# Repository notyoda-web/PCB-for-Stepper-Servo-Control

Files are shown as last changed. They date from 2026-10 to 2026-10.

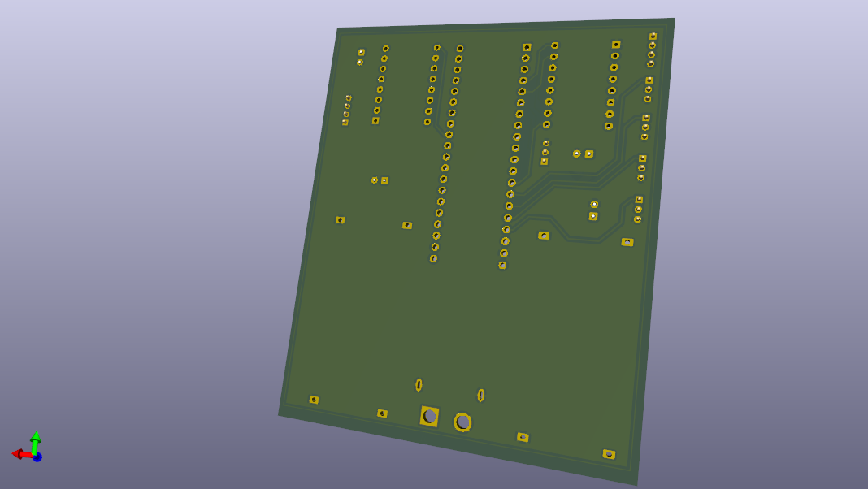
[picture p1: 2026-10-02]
testeurobot1.png

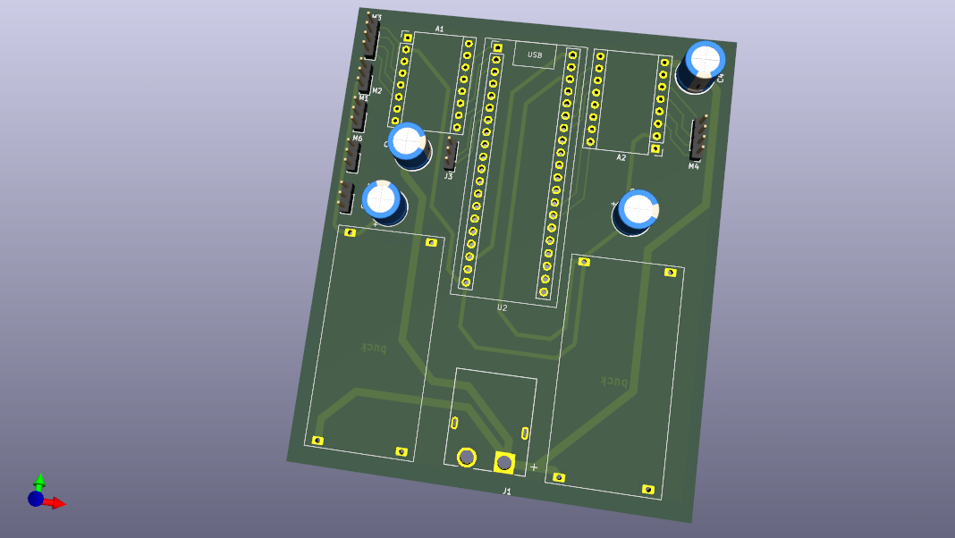
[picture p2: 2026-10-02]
testeurobot.png

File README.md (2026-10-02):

# STM32 Black Pill Stepper & Servo Control Board - Pin Mapping & Connections

This document details the exact pin-to-pin net connections and interface routing between the STM32 Black Pill microcontroller, the power subsystems, the A4988 stepper drivers, the servo headers, and communication peripherals, as established in the KiCad schematic .

---

## Power Input & Regulation Subsystem

* **J1 (XT60PW-M Power Input):**
  * Pin `P` (Positive / 12V rail): Connects directly to the main 3S LiPo battery input line, feeding the input terminals of both buck converters (`12V`) and the VMOT pins of A4988 drivers `A1` and `A2`.
  * Pin `N` (Negative / GND): Connects to the system common ground (`GND`).
* **3.3V Buck Converter:**
  * Input: Connected to `12V` rail from J1.
  * Output: Connected to the `3.3V` net, providing power to the Black Pill `VDD`/`3.3V` pins and auxiliary logic. Bulk smoothing capacitor `C1` is placed across the output.
* **5V Buck Converter:**
  * Input: Connected to `12V` rail from J1.
  * Output: Connected to the `5V` net, supplying power to the four hobby servo motor headers (`N1`, `N2`, `N5`, `N6`). Bulk smoothing capacitor `C2` is placed across the output.

---

# Power Distribution & Decoupling Rationale

This document outlines the engineering reasons for using dual buck converters and four electrolytic capacitors in the STM32 Black Pill stepper and servo control board, as shown in the schematic and PCB layout.

---

## 1. The Use of Two Buck Converters

The board utilizes two separate step-down (buck) converters fed by the 3S LiPo battery (`12V` net) to establish distinct power domains:

* **Isolation of Inductive Noise:** Stepper motors and hobby servos generate massive voltage transients, back-EMF, and high-frequency current spikes on their power rails during switching and stalling. By separating the regulation paths, noisy high-power actuator rails are prevented from coupling directly into sensitive digital logic.
* **Dedicated Voltage Domains:** 
  * **5V Buck Converter:** Powers the four hobby servos (`N1`, `N2`, `N5`, `N6`), which draw heavy peak currents under load. Supplying them from a dedicated regulator prevents voltage sags from resetting the microcontroller.
  * **3.3V Buck Converter:** Supplies a clean, stable regulated voltage exclusively to the Black Pill microcontroller (`VDD`/`3.3V`), protecting its internal ADC, core logic, and communication peripherals from brownouts.

---

## 2. The Use of Four Electrolytic Capacitors (`C1`, `C2`, `C3`, `C4`)

The four bulk electrolytic capacitors serve specific filtering and energy-storage functions across the power architecture:

* **Regulator Output Smoothing (`C1` and `C2`):**
  * **`C1` (3.3V Rail):** Placed at the output of the 3.3V buck converter to filter out residual switching ripple, ensuring a steady, low-noise supply for the Black Pill.
  * **`C2` (5V Rail):** Positioned at the 5V regulator output to provide bulk charge reservoirs that instantly compensate for current surges when servos suddenly start moving or change direction.
* **Motor Driver Local Decoupling (`C3` and `C4`):**
  * **`C3` and `C4` (VMOT Decoupling):** Connected directly across the motor supply (`VMOT`) and ground (`GND`) of the two A4988 driver modules (`A1` and `A2`). 
  * **Transient Suppression:** Stepper drivers rapidly chop high currents through inductive windings, creating high-frequency voltage spikes that can destroy silicon. These bulk capacitors act as local energy buffers right next to the driver chips, absorbing back-EMF spikes and stabilizing the input voltage during rapid microstepping steps.

## Stepper Motor Subsystem (A4988 Drivers & Connectors)

* **Driver A1 (Left Stepper Driver):**
  * **Power & Decoupling:** `VMOT` connected to `12V` with electrolytic decoupling capacitor `C3` tied to `GND`; `VDD` connected to `3.3V`.
  * **Control Pins:** 
    * `STEP` $\rightarrow$ Connected to MCU pin `PA1`.
    * `DIR` $\rightarrow$ Connected to MCU pin `PA2`.
    * `ENABLE` $\rightarrow$ Connected to MCU pin `PA6`.
    * Microstepping (`MS1`, `MS2`, `MS3`) $\rightarrow$ Tied to MCU pins `pb2`, `pb1`, `pb0` respectively.
    * `SLEEP` & `RESET` $\rightarrow$ Tied together on the module.
  * **Motor Output (`N4`):**
    * Pins `1B`, `1A`, `2A`, `2B` mapped directly from A1 driver pins 3, 4, 5, 6 to motor connector `N4` (`1A1_181`, `1A`, `2A`, `2B`).

* **Driver A2 (Right Stepper Driver):**
  * **Power & Decoupling:** `VMOT` connected to `12V` with electrolytic decoupling capacitor `C4` tied to `GND`[cite: 3]; `VDD` connected to `3.3V`.
  * **Control Pins:**
    * `STEP` $\rightarrow$ Connected to MCU pin `PB15`.
    * `DIR` $\rightarrow$ Connected to MCU pin `PB14`.
    * `ENABLE` $\rightarrow$ Connected to MCU pin `PB5`.
    * Microstepping (`MS1`, `MS2`, `MS3`) $\rightarrow$ Tied to MCU pins `pb14` (shared/routed), `pb13`, `pb12`.
    * `SLEEP` & `RESET` $\rightarrow$ Tied together on the module.
  * **Motor Output (`N3`):**
    * Pins `1B`, `1A`, `2A`, `2B` mapped directly from A2 driver pins to motor connector `N3`.

---

## Servo Motor Subsystem

All four servo headers share a common power (`5V`) and ground (`GND`) bus, with individual PWM control lines driven directly by MCU GPIO/timer pins:

* **Servo Header N2:** Pin 1 (Signal) $\rightarrow$ MCU pin `PB6`; Pin 2 $\rightarrow$ `5V`; Pin 3 $\rightarrow$ `GND`.
* **Servo Header N1:** Pin 1 (Signal) $\rightarrow$ MCU pin `PB7`; Pin 2 $\rightarrow$ `5V`; Pin 3 $\rightarrow$ `GND`.
* **Servo Header N6:** Pin 1 (Signal) $\rightarrow$ MCU pin `PB8`; Pin 2 $\rightarrow$ `5V`; Pin 3 $\rightarrow$ `GND`.
* **Servo Header N5:** Pin 1 (Signal) $\rightarrow$ MCU pin `PB9`; Pin 2 $\rightarrow$ `5V`; Pin 3 $\rightarrow$ `GND`.

---

## Communication Interface (UART)

* **J3 (UART Header):**
  * Pin 1 (`Rx`) $\rightarrow$ Connected to Black Pill MCU pin `PA9` (`Tx` of USART1) for host ingestion.
  * Pin 2 (`Tx`) $\rightarrow$ Connected to Black Pill MCU pin `PA10` (`Rx` of USART1) for telemetry transmission.
  * Pin 3 (`GND`) $\rightarrow$ Connected to system common ground (`GND`).

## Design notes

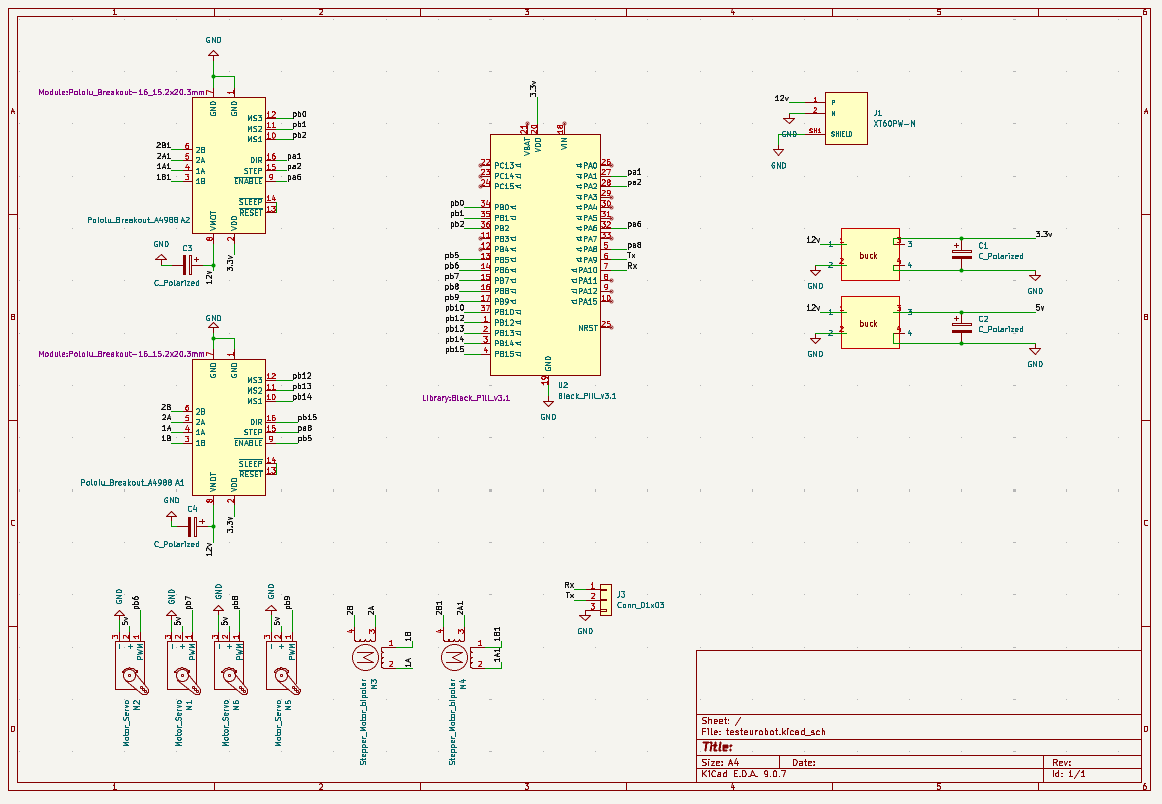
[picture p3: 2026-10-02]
Capture d'écran 2026-10-02 215708.png

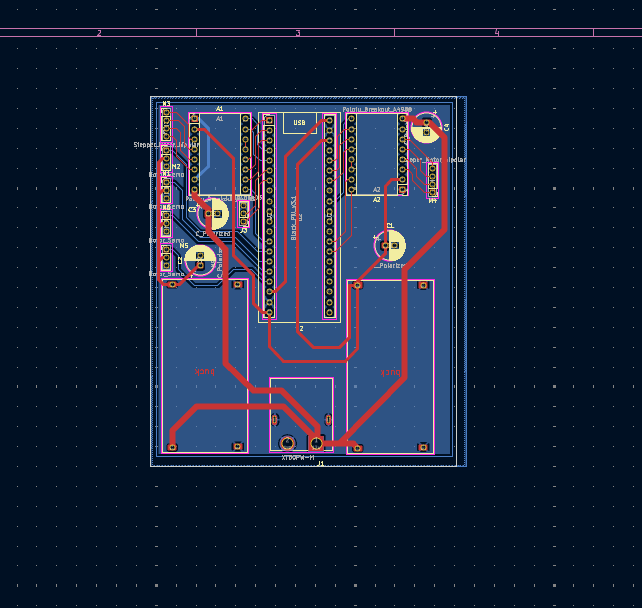
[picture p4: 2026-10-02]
Capture d'écran 2026-10-02 215855.png

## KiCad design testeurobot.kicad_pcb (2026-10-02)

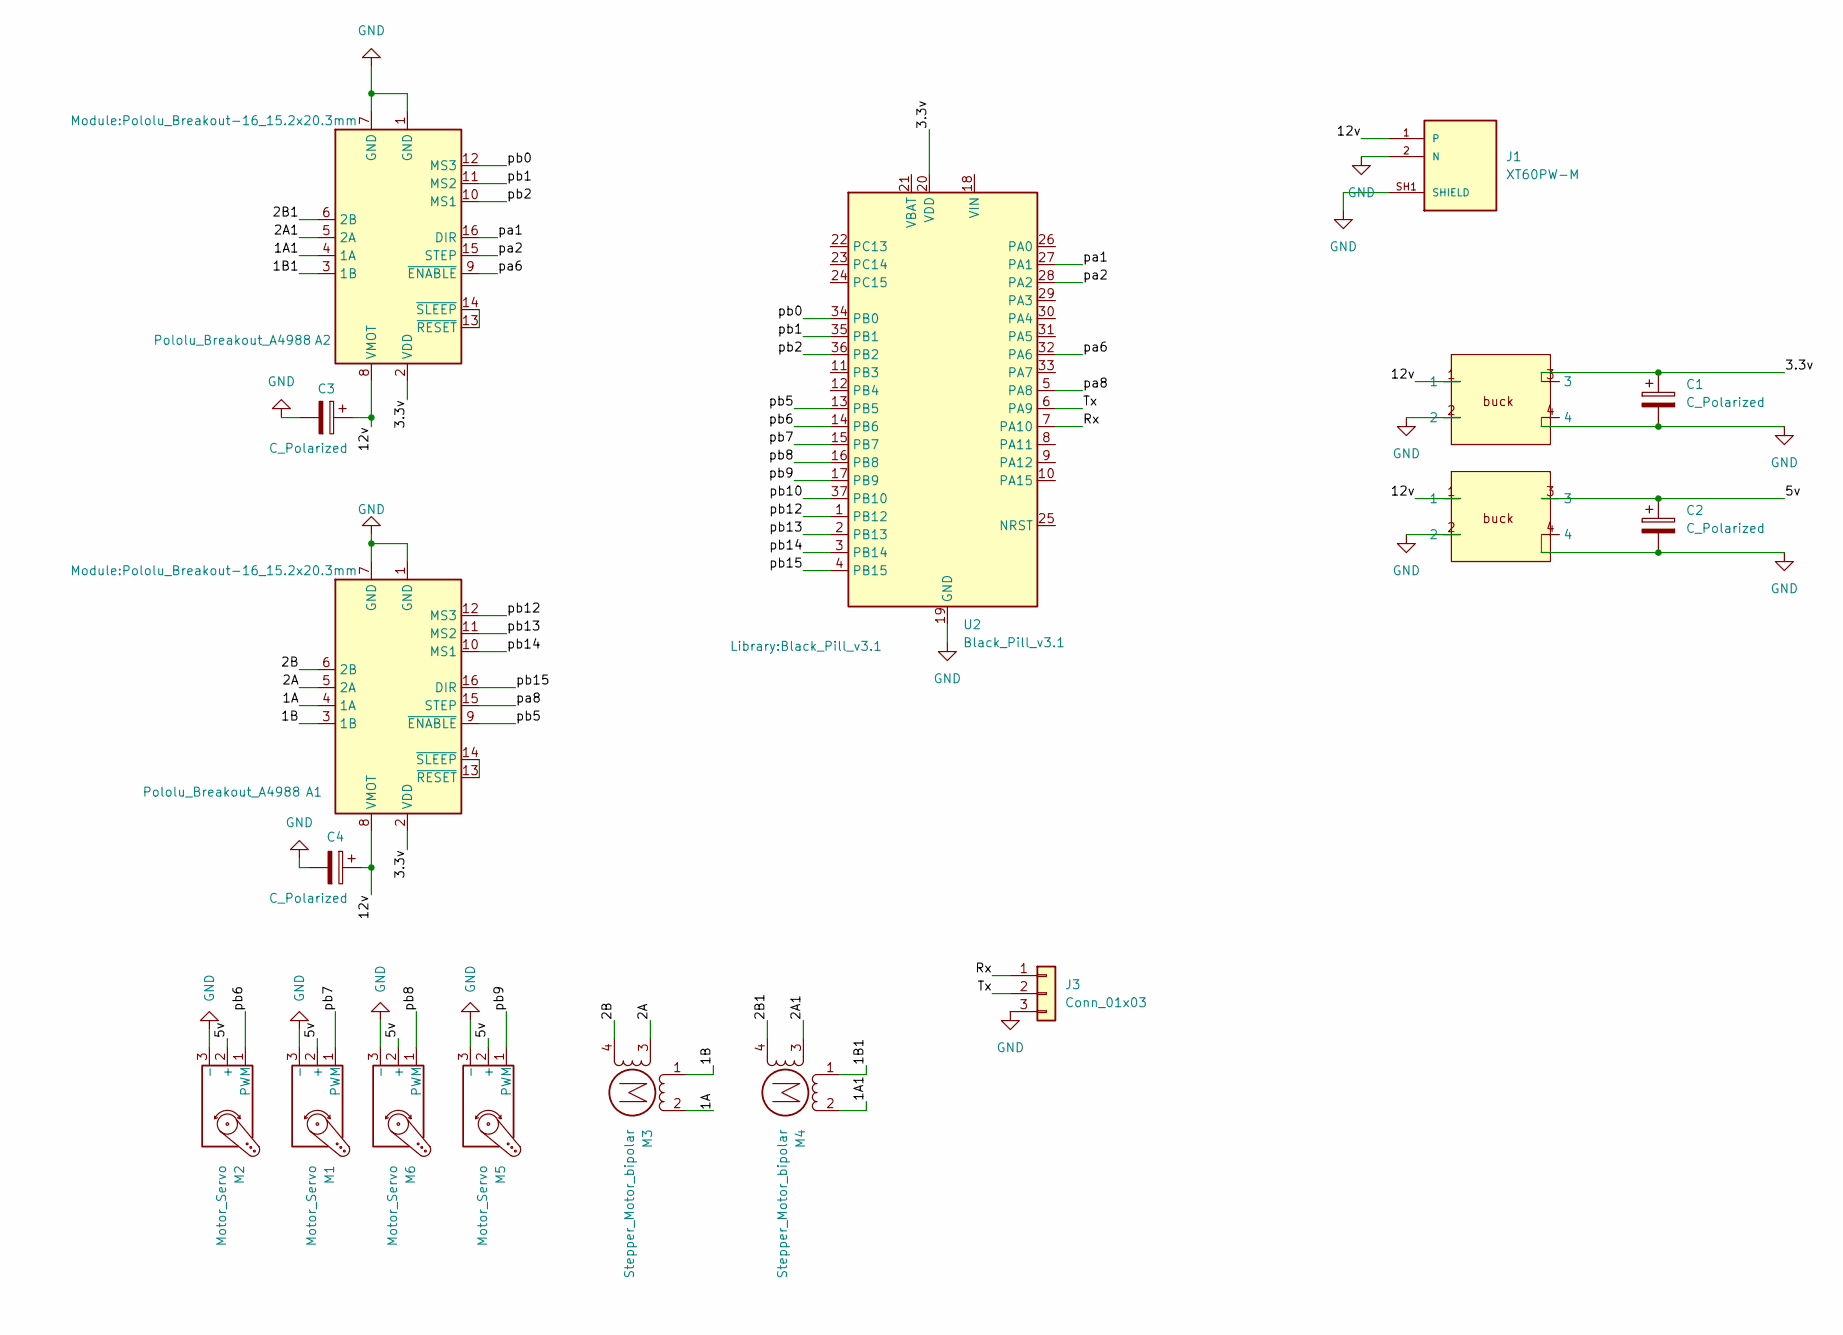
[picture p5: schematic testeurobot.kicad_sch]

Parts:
A1, A2: Pololu_Breakout_A4988; Pololu_Breakout-16_15.2x20.3mm
C1, C2, C3, C4: C_Polarized; CP_Radial_D7.5mm_P2.50mm
J1: XT60PW-M; AMASS_XT60PW-M; PARTREV 1.2
J3: Conn_01x03; PinHeader_1x03_P2.00mm_Vertical
M1, M2, M5, M6: Motor_Servo; PinHeader_1x03_P2.00mm_Vertical
M3, M4: Stepper_Motor_bipolar; PinHeader_1x04_P2.00mm_Vertical
U1, U3: buck
U2: Black_Pill_v3.1

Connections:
/1A: A1.4 (1A), M3.2 (-)
/1A1: A2.4 (1A), M4.2 (-)
/1B: A1.3 (1B), M3.1
/1B1: A2.3 (1B), M4.1
/2A: A1.5 (2A), M3.3
/2A1: A2.5 (2A), M4.3
/2B: A1.6 (2B), M3.4
/2B1: A2.6 (2B), M4.4
/5v: C2.1, M1.2 (+), M2.2 (+), M5.2 (+), M6.2 (+), U3.3
/12v: A1.8 (VMOT), A2.8 (VMOT), C3.1, C4.1, J1.1, U1.1, U3.1
/Rx: J3.1, U2.7 (PA10)
/Tx: J3.2, U2.6 (PA9)
/pa1: A2.16 (DIR), U2.27 (PA1)
/pa2: A2.15 (STEP), U2.28 (PA2)
/pa6: A2.9 (~ENABLE), U2.32 (PA6)
/pa8: A1.15 (STEP), U2.5 (PA8)
/pb0: A2.12 (MS3), U2.34 (PB0)
/pb1: A2.11 (MS2), U2.35 (PB1)
/pb2: A2.10 (MS1), U2.36 (PB2)
/pb5: A1.9 (~ENABLE), U2.13 (PB5)
/pb6: M2.1 (PWM), U2.14 (PB6)
/pb7: M1.1 (PWM), U2.15 (PB7)
/pb8: M6.1 (PWM), U2.16 (PB8)
/pb9: M5.1 (PWM), U2.17 (PB9)
/pb10: U2.37 (PB10)
/pb12: A1.12 (MS3), U2.1 (PB12)
/pb13: A1.11 (MS2), U2.2 (PB13)
/pb14: A1.10 (MS1), U2.3 (PB14)
/pb15: A1.16 (DIR), U2.4 (PB15)
GND: A1.1 (GND), A1.7 (GND), A2.1 (GND), A2.7 (GND), C1.2, C2.2, C3.2, C4.2, J1.2 (N), J1.SH1 (SHIELD), J1.SH2 (SHIELD), J3.3, M1.3 (-), M2.3 (-), M5.3 (-), M6.3 (-), U1.2, U1.4, U2.19 (GND), U2.39 (GND), U3.2, U3.4
unnamed: A1.13 (~RESET), A1.14 (~SLEEP)
unnamed: A2.13 (~RESET), A2.14 (~SLEEP)
VDD: A1.2 (VDD), A2.2 (VDD), C1.1, U1.3, U2.20 (VDD), U2.38 (VDD)
VIN: U2.18 (VIN), U2.40 (VIN)

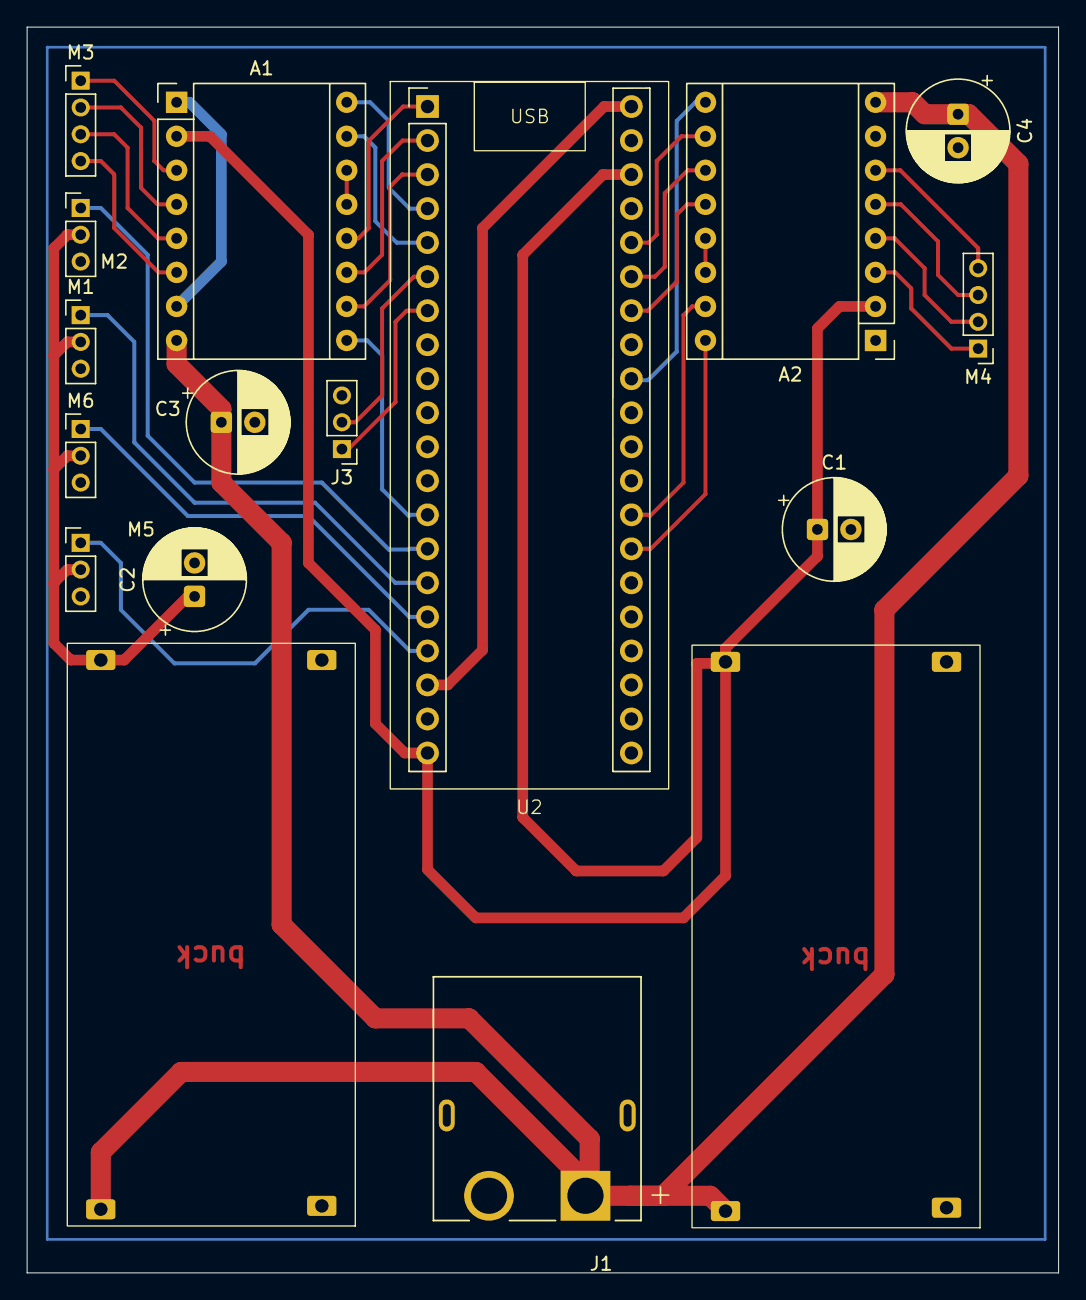
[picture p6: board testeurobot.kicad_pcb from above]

Board: 2 copper layers, 77.0 x 93.0 mm, 17 parts (0 on the bottom side), 33 nets.

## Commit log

2026-10-02 Rename Capture d'écran 2026-10-02 215708.png to schematic
2026-10-02 Add testeurobot KiCad PCB project files
    [testeurobot.kicad_pcb, testeurobot.kicad_sch]
